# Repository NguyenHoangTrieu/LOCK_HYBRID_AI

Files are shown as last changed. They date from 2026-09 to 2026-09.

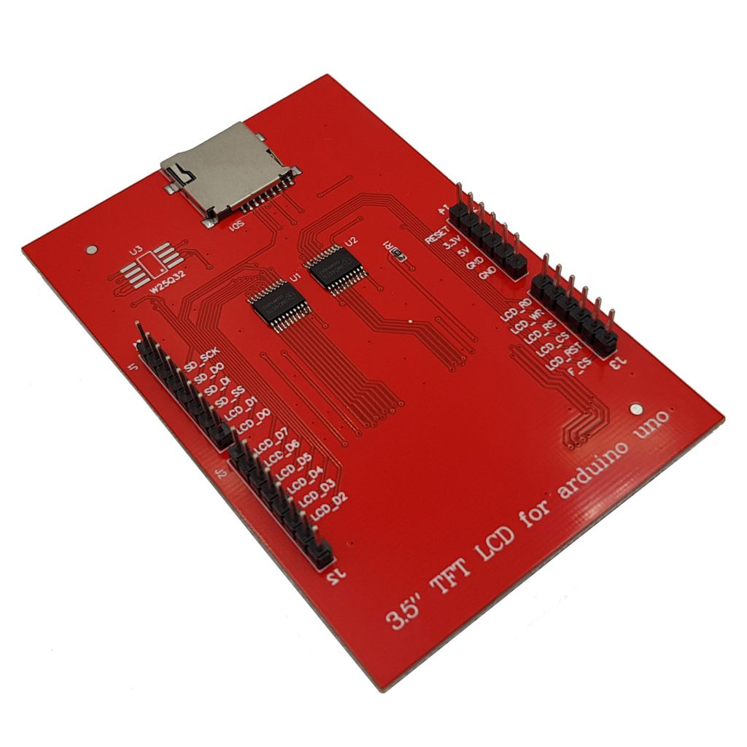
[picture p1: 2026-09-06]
EDGE_NODE/image.png

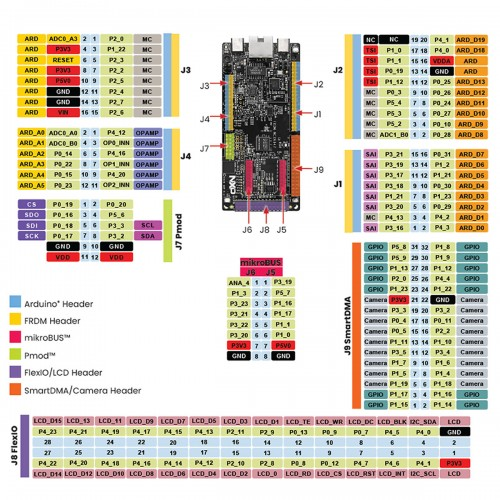
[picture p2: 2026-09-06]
EDGE_NODE/image-1.png

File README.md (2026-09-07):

# LOCK_HYBRID_AI

Face and RFID attendance / access-control system. A door-mounted **Edge AI Node**
detects faces and reads RFID cards; a **Cloud Backend** identifies people, stores
attendance records, and serves an admin web app. Full detail lives in
[ARCHITECTURE.md](ARCHITECTURE.md) (design) and [SYSTEM_REQUIREMENTS.md](SYSTEM_REQUIREMENTS.md)
(requirements, IEEE 830 / ISO-IEC-IEEE 29148 style).

## Why the split

The door device can run a small model that finds faces, but not the much
larger model that identifies them, and it can't hold the user database. So
the device answers *"is someone there?"* and the server answers *"who is
it?"* (CON-7, CON-8 in the SRS).

```mermaid
graph LR
    EDGE["Edge AI Node<br/>detects faces, reads cards, opens the latch"]
    CLOUD["Cloud Backend<br/>identifies people, stores records, serves admin UI"]
    EDGE -->|"face image or card UID"| CLOUD
    CLOUD -->|"decision + unlock command"| EDGE
```

## Repository Layout

```
LOCK_HYBRID_AI/
  ARCHITECTURE.md          <- system design, sequence/state diagrams, build order
  SYSTEM_REQUIREMENTS.md   <- SRS: functional, performance, accuracy, safety requirements
  EDGE_NODE/                <- door-side firmware (FRDM-MCXN947 + camera + RFID + LCD + latch)
    Camera_AI_Test1/          <- camera capture + on-device NPU face-detection bring-up project
  PCB_DES/                  <- hardware / PCB design
    LOCK_EDGE_BASEBOARD/
  CLOUD_SERVER/              <- recognition service, database, admin web app (not yet started)
```

### EDGE_NODE

`EDGE_NODE/Camera_AI_Test1` is the bring-up project for the edge device's
camera + on-NPU face-**detection** pipeline (OV7670 → SmartDMA → Edge
Impulse FOMO model on the Neutron NPU → LCD status / SD snapshot), copied
in from the standalone `Camera_AI_Test1` prototype. It proves out CON-1,
CON-3, and CON-7 from the SRS: an FRDM-MCXN947 board driving an OV7670
camera and running face detection on the integrated NPU without the
general-purpose CPU doing the main computation.

This copy keeps its own `README.md` (build/flash instructions, pinout,
hardware notes) and `ARCHITECTURE.md` (design decisions, NPU integration
details), but drops `KNOWLEDGE.md` (a general concepts primer) and
`WORKLOG.md` (the standalone prototype's dated bring-up log) — those
documented the independent history of the prototype and don't apply once
folded into this repo. The firmware source, board port, and AI model files
are unchanged from the original project.

What still needs to be added on top of this bring-up code to satisfy the
Edge AI Node requirements in the SRS: RFID reader (MFRC522) integration
(HI-2), servo-motor latch control with fail-locked behavior (HI-3, HI-4,
SR-6), the state machine described in ARCHITECTURE.md §2.4, network
communication with the Cloud Backend over the ESP32-C5 DevKit 2.0 (CON-2, CI-1
to CI-5), and offline event buffering (FR-19 to FR-25).

### CLOUD_SERVER

Not yet started. Per ARCHITECTURE.md §3, this will hold the API layer,
recognition service (align → embed → match), attendance service, database,
and the admin web app.

### PCB_DES

Hardware/PCB design files for the edge baseboard (`LOCK_EDGE_BASEBOARD`).

## Build Order

See ARCHITECTURE.md §6 for the full sequencing rationale. In short: bring
up peripherals in isolation, stand up a stub server API, wire the network
path end to end, get card-based attendance fully working with no AI
involved, then bring in the detection model on the device and recognition
on the server.

## Known Limitations (by design, this release)

- **No presentation-attack (spoofing) detection** — a photo of an enrolled
  person may be sufficient to obtain access (SR-7). Sites needing
  protection against this must not rely on face recognition as the sole
  access control.
- Face-based access is not available while offline; only card-based access
  can optionally work offline, using cached authorization data (FR-23,
  FR-24).

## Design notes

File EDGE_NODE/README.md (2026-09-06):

# Camera_AI_Test1

Real-time face-detection camera on **FRDM-MCXN947**. Captures frames from an
OV7670 camera via SmartDMA, runs a single-class ("face") Edge Impulse FOMO
model per frame, and shows the result as a text status line on a TFT panel.
On detection, saves a snapshot (with a box drawn around the face) to the
TFT panel's onboard microSD card, rate-limited to 1 photo/sec.

**Status:** camera + AI + SD snapshot confirmed working on real hardware
(single-core build). The display moved from an 8-bit-parallel shield to a
2.4" SPI TFT module sharing one bus with its microSD slot and XPT2046
touch controller — confirmed working, currently at **7fps** (target
~24fps, next step paused pending further work; see Known Limitations).
Bus-sharing and touch are build-verified only, not yet tested on hardware.
The dual-core RTOS build (see below) is further along — now showing a
live image on real hardware too.

## Overview

Pipeline: `Camera (OV7670/SmartDMA)` → `AI inference (CPU or Neutron NPU)` → `LCD status text`.

Inference runs on either the CPU (CMSIS-NN) or the Neutron NPU (default,
~4ms/inference on real hardware).

- [ARCHITECTURE.md](ARCHITECTURE.md) — design decisions, memory-conflict
  pitfalls, NPU integration details for this specific build.
- [KNOWLEDGE.md](KNOWLEDGE.md) — plain-language explainer of the underlying
  concepts (DVP camera protocol, coprocessors, NPU/quantization, embedded
  RAM/power domains, SWD debug, DCDC voltage conflicts) for anyone new to
  this domain.
- [WORKLOG.md](WORKLOG.md) — full dated bring-up history.
- Original request: [requirement.md](requirement.md).

## Hardware

| Component | Model / Part | Notes |
|---|---|---|
| Board | FRDM-MCXN947 | |
| Camera | OV7670 | → **J9** (SmartDMA/Camera header) |
| Display | 2.4" TFT, 240x320, SPI (ILI9341-family) | → Arduino header (hardware LPSPI1, shared bus) |
| Touch | XPT2046 (on the same TFT module) | → Arduino header, same shared SPI bus; wired up but not read from anywhere in the app - see Known Limitations |
| microSD | TFT panel's onboard slot (SPI mode, FAT-formatted card) | → Arduino D10..D13, same shared SPI bus (hardware LPSPI1) |
| Debug probe | On-board MCU-Link (CMSIS-DAP) | flashing + serial console |

**Board rework required:** change `SJ16`, `SJ26`, `SJ27` from the right side
to the left side before attaching the camera to J9 (per NXP's reference
design).

### Pinout — Camera (OV7670 → J9)

| Camera signal | MCU pin | J9 pin # |
|---|---|---|
| SIOC / SIOD (SCCB) | P3_2 / P3_3 (LP_FLEXCOMM7) | 19 / 20 |
| XCLK | P2_2 (CLKOUT) | 16 |
| PCLK | P0_5 | — |
| HREF | P0_11 | — |
| VSYNC | P0_4 | — |
| D0..D7 | P1_4, P1_5, P1_6, P1_7, P3_4, P3_5, P1_10, P1_11 | 7,8,9,10,11,12,13,14 |
| 3V3 / GND | — | 21 / 22 |

### Pinout — TFT + microSD + touch (Arduino header, ONE shared hardware SPI bus)

2.4" SPI TFT module (ILI9341-family LCD + onboard microSD slot + XPT2046
touch controller). Not a stacking Arduino shield like the previous panel —
wire each pin to the FRDM-MCXN947's Arduino header with jumper wires.

**All three devices share one physical SPI bus** (SCK/MOSI/MISO on Arduino
D13/D11/D12 — the board's only Arduino-header SPI peripheral, hardware
LPSPI1), each with its own chip-select. This is standard wiring for this
class of module (the LCD's SDI/SCK/SDO, the microSD slot's SD_MOSI/SD_SCK/
SD_MISO, and touch's T_DIN/T_CLK/T_DO are 3 silkscreen labels for the same
3 electrical signals) and keeps pin usage low — only 10 Arduino pins used
total, `D0`-`D7` entirely free. See `source/spi1_bus.c` for how the sharing
works (bus init, per-transaction baud-rate reclaiming, chip-select
handling) — **this bus-sharing logic is new and untested on real
hardware**, more so than a single-device SPI driver would be; see Known
Limitations before assuming it's solid.

| Panel pin | Arduino pin | MCU pin | Notes |
|---|---|---|---|
| SCK / SD_SCK / T_CLK | D13 | P0_25 | shared bus, hardware LPSPI1 SCK |
| SDI(MOSI) / SD_MOSI / T_DIN | D11 | P0_24 | shared bus, hardware LPSPI1 SDO (MCU→devices) |
| SDO(MISO) / SD_MISO / T_DO | D12 | P0_26 | shared bus, hardware LPSPI1 SDI (devices→MCU); needs the internal pull-up `pin_mux.c` already enables here |
| LCD CS | A3 | P0_22 | manual GPIO, LCD-only |
| LCD DC | A2 (legacy single-core build) / **D3** (dual-core build) | P0_14 / **P1_23** | manual GPIO, command/data select - moved to GPIO1 for the dual-core build while this pin's real blocker (core1 has no SAU, needs an explicit `PCNS` Non-Secure grant from core0 - see WORKLOG.md's EIGHTH FOLLOW-UP) was still being tracked down; the GPIO1 move itself probably wasn't the fix, granting `PCNS` was, but it's confirmed working as-is so left unchanged |
| LCD RESET | A4 | P0_15 | manual GPIO |
| LCD LED (backlight) | A5 | P0_23 | manual GPIO, driven high in `LCD_Init()` |
| SD_CS | D10 | P0_27 | **real hardware** LPSPI1 PCS0 - SD-only, see below |
| T_CS | D9 | P0_10 | manual GPIO, touch-only |
| T_IRQ | D8 | P0_28 | manual GPIO input (pull-up enabled), active low when touched |
| VCC, GND | board power header | direct | 3.3V or 5V per the panel's regulator — check the specific module |

Only the microSD slot uses the peripheral's real hardware chip-select
(PCS0/D10) — `SDSPI_Init()` needs to flip its active polarity at runtime,
which only works through actual PCS hardware. The LCD and touch each use a
plain GPIO pin for CS instead, toggled manually around every transfer.

**MADCTL (`0x36`) in `lcd_spi_hw.c`'s `LCD_InitPanel()`**: `MV=1`
(rotation) confirmed correct on real hardware. `BGR` was wrong for this
panel (carried over from the old one) — caused a blue/cyan color cast,
fixed by clearing it (`0x28` → `0x20`). If colors or orientation still
look off, adjust `MV`/`MX`/`MY`/`BGR` there.

**Touch (XPT2046) is wired up but unused** — no touch UI in this
pipeline. `touch_xpt2046.c` provides raw, uncalibrated read functions for
a future feature; X/Y channel mapping is a common-convention guess,
unverified on this panel.

## Getting Started

### Prerequisites

- `arm-none-eabi-gcc`, `west` (via the venv at `../../tools/westenv`)
- Local `mcuxsdk` checkout at `../mcuxsdk`
- `pyocd` for flashing over the on-board MCU-Link

### Build / Flash / Run

```bash
./firmware/camera_ai_demo/build.sh          # build, then flash
./firmware/camera_ai_demo/build.sh build    # build only
./firmware/camera_ai_demo/build.sh flash    # flash the last build
./firmware/camera_ai_demo/build.sh monitor  # serial console (115200-8-N-1)
```

`build.sh` runs `west build -b frdmmcxn947 firmware/camera_ai_demo
--toolchain armgcc -Dcore_id=cm33_core0` from the `../mcuxsdk` west
workspace, then flashes the `.elf` via pyOCD, auto-selecting the probe by
its MCU-Link unique ID. See `../../touch_rgb/README.md` for the
probe-permissions/udev-rule note if `pyocd` needs `sudo`.

**If flashing fails with `DebugPortStart`/`ResetCatchClear`/`ResetSystem`
`WAIT ACK`/`FAULT ACK` errors** — a standing probe/pyOCD/CMSIS-Pack quirk on
this board, unrelated to firmware correctness — see
[ARCHITECTURE.md §5](ARCHITECTURE.md#5-debugging--tooling-notes) for the
working recipe (`nxpdebugmbox` + specific pyOCD flags).

### Dual-core RTOS build (see WORKLOG.md)

A separate, opt-in build (`-DDUALCORE_RTOS=ON`, default `OFF`) boots core1
and splits the app across both cores: core1 runs camera capture + LCD push
+ SD snapshot (`source/main_core1.c`), core0 runs AI inference only
(`source/main_core0.c`), both under FreeRTOS, talking over MCMGR
mailbox-event doorbells (`source/shared/ipc_events.*`) and a shared frame
buffer (`source/shared/ipc_layout.h`) — no RPMsg-Lite. Full migration
history/stage-by-stage bring-up: [ARCHITECTURE.md](ARCHITECTURE.md),
[WORKLOG.md](WORKLOG.md).

This is a **completely separate build directory and command set** from the
single-core build above — the two never share build artifacts and flashing
one never disturbs the other:

```bash
./firmware/camera_ai_demo/build.sh dualcore-build   # build core1, then core0 (core0 embeds core1's image)
./firmware/camera_ai_demo/build.sh dualcore-flash   # flash core0's combined .elf - one flash op, core1 rides along
./firmware/camera_ai_demo/build.sh dualcore-all     # both of the above
./firmware/camera_ai_demo/build.sh monitor          # same serial console works for either build
```

Notes specific to this build:

- **core1 must always build before core0** — core0's link step `.incbin`s
  core1's raw `.bin` (see `board_port/cm33_core0/app.h`), which needs
  core1's build directory to already exist. `dualcore-build` always does
  both in the right order and also force-deletes core0's cached
  `fsl_incbin.S` object file first, since Ninja has no way to know that
  `.incbin` depends on core1's binary — without that, core0 can silently
  re-link a **stale** embedded core1 image after only core1's source
  changed. Always use `dualcore-build` (not a manual `west build` for a
  single core) when iterating, especially on core1 code.
- No `rebuild`/`clean` equivalent for `build_dualcore/` yet — remove it by
  hand (`rm -rf firmware/camera_ai_demo/build_dualcore`) for a truly clean
  dual-core rebuild.
- **The `LCD_CAMERA_PREVIEW`, `AI_MODEL_USE_NPU`, `LCD_ARDUINO_HEADER_BITBANG`,
  and `USB_STREAM_DIAGNOSTIC_DISABLE` flags documented above do NOT apply
  to this build** — `CMakeLists.txt`'s `DUALCORE_RTOS` branch `return()`s
  before any of those `option()`s are even declared. Core1's
  `CameraLcdTask` always runs one fixed loop (camera preview + AI overlay
  + rate-limited snapshot together); there is currently no dual-core
  equivalent of the AI-off, preview-only diagnostic build.
- **Status: Stage 5, CONFIRMED SHOWING A LIVE IMAGE on real hardware
  (2026-09-06)** — camera, LCD push, the core0 AI round-trip, SD
  snapshot, and the on-screen image are all confirmed working. Still
  open: LCD tearing under the cross-core IPC interrupt hasn't been
  re-checked now that the image is visible, and SD write reliability
  degrades after the first few snapshots in a session. See WORKLOG.md's
  latest entries before assuming full stability.
- **Adding a new GPIO pin for core1 to drive? Read this first.** core1
  has no SAU, so it's permanently Non-Secure — GPIO blocks Non-Secure pin
  access per-pin by default (`PCNS` register). An ungranted pin doesn't
  error, it just silently does nothing. Grant it from **core0** before
  `MCMGR_StartCore()` — see `main_core0.c`'s `GPIO0->PCNS`/`GPIO1->PCNS`
  lines, WORKLOG.md's EIGHTH FOLLOW-UP entry, and KNOWLEDGE.md §9.

### Expected output on success

```
Camera_AI_Test1 - FRDM-MCXN947
Camera: OV7670 on J9 SmartDMA/Camera header
Display: Arduino-header LCD status text (camera + AI hook)

Camera: OV7670 detected on J9 (PID=0x76 VER=0x73 confirmed), 320x240 @ 30 fps.
AI_MODEL_Init: Neutron NPU face detector ready (72x72 input, 1 class(es), arena used 94388/122880 bytes)
LCD: hardware SPI (LPSPI1, shared bus) on the Arduino header
AI_MODEL_RunInference: total classifier time = 3957us (3ms)
AI result: box[0] label=face x=<N> y=<N> w=<N> h=<N> score=<N>%
```

LCD shows two text lines — `FACE: 1`/`FACE: 0`, and `CAPTURE: 1`/`CAPTURE: 0`
(lit for 4s right after a snapshot is saved, see "Snapshot on Face
Detection" below) — not a live image.

## Configuration

Pass any of these to `build`/`rebuild`/`all` as `-D<FLAG>=ON|OFF`.

| Flag | Default | Effect |
|---|---|---|
| `AI_MODEL_USE_NPU` | `ON` | Inference backend: Neutron NPU (`ON`, ~4ms/inference) vs. CPU + CMSIS-NN via Edge Impulse SDK (`OFF`). Same detection logic either way. |
| `LCD_CAMERA_PREVIEW` | `OFF` | Skip AI, stream raw camera feed to the LCD as fast as frames arrive — for focusing the lens by eye. Prints `LCD preview: N fps` once/sec over UART — see Known Limitations for the fps math/target. |
| `LCD_ARDUINO_HEADER_BITBANG` | `ON` | `ON`: drive TFT via hardware SPI on the Arduino header, shared with the microSD/touch bus (default). `OFF`: J8 header (FlexIO/bit-bang) — abandoned, no touch/SD sharing there, see [ARCHITECTURE.md §4](ARCHITECTURE.md#4-known-constraints--trade-offs). |
| `USB_STREAM_DIAGNOSTIC_DISABLE` | `ON` | `OFF` opts into the abandoned UVC webcam streaming path (doesn't drive the LCD) — see [ARCHITECTURE.md §4](ARCHITECTURE.md#4-known-constraints--trade-offs). |

`AI_MODEL_USE_NPU` and `LCD_CAMERA_PREVIEW` are independent of the LCD/USB
flags; combining `LCD_CAMERA_PREVIEW=ON` with
`USB_STREAM_DIAGNOSTIC_DISABLE=OFF` builds but isn't a meaningful
combination.

### Example commands

```bash
# Default build (Neutron NPU, camera+AI+LCD status text, no USB)
./firmware/camera_ai_demo/build.sh build

# Lens-focus diagnostic: raw camera feed straight to the LCD, no AI
./firmware/camera_ai_demo/build.sh build -DLCD_CAMERA_PREVIEW=ON

# CPU + CMSIS-NN inference instead of the Neutron NPU
./firmware/camera_ai_demo/build.sh build -DAI_MODEL_USE_NPU=OFF

# J8 header (FlexIO) instead of the Arduino header's SPI panel - abandoned, see ARCHITECTURE.md §4
./firmware/camera_ai_demo/build.sh build -DLCD_ARDUINO_HEADER_BITBANG=OFF

# Flags combine freely - build only (no flash), CPU backend + lens-focus preview
./firmware/camera_ai_demo/build.sh build -DAI_MODEL_USE_NPU=OFF -DLCD_CAMERA_PREVIEW=ON
```

`build` builds without flashing; `all` (or bare `./build.sh`) builds then
flashes; `rebuild` cleans `build/` first - needed when switching flags
that change which files compile, since flags otherwise stick in the CMake
cache.

## AI Model

Edge Impulse project **"Face_Detection_NXP"** (ID `1095726`, deploy v2),
FOMO detector, 72x72 int8 input, single class `face`, trained on
WIDER FACE + DarkFace (**both CC-BY-NC-ND/research-only — not cleared for
commercial use as-is**).

| | Neutron NPU (default) | CPU + CMSIS-NN |
|---|---|---|
| Build flag | (default) | `-DAI_MODEL_USE_NPU=OFF` |
| Source | `source/ai/model_runner_npu.cpp` | `source/ai/model_runner.cpp` |
| Tensor arena | 120KB static (`m_data`), 94,388 bytes used | 112,460 bytes (`m_sramx` primary + `m_data` overflow) |
| Measured on hardware | ~3.96ms/inference | not yet separately measured for this model |

To swap in a different/retrained model: re-export from Edge Impulse Studio
(new C++ library for the CPU path; new `.tflite` run through
`neutron_converter` for the NPU path) and update
`model_runner.cpp`/`model_runner_npu.cpp` if tensor shapes or class labels
changed. See [ARCHITECTURE.md §2](ARCHITECTURE.md#2-components) for how
the NPU conversion and integration actually work.

## Snapshot on Face Detection

On face detection, `snapshot.c` draws a green box (via `bbox_overlay.c`)
into the frame buffer and saves it as an uncompressed 16-bit BMP
(`FACE0001.BMP`, ...) to the SD card, rate-limited to 1 capture/sec.
Filenames never overwrite a previous session's snapshots.

The box is the model's raw grid-cell box (small relative to a real face,
since FOMO doesn't regress an actual box size) - a cosmetic expansion was
tried and reverted on purpose. See
[ARCHITECTURE.md §2](ARCHITECTURE.md#2-components).

The LCD shows a `CAPTURE: 1` status line for 4s after each save (the box
itself is only in the saved file, never drawn on the LCD). No SD card →
logged once at boot, then snapshot capture silently no-ops every frame
after.

Every save logs how long the actual SD card write took (DWT cycle
counter, same technique `AI_MODEL_RunInference` uses):
```
Snapshot: saved FACE0030.BMP (write took 187342us, 187ms)
```
Originally ~3.3s/save - the SD bus was stuck at the 400kHz identification
speed instead of switching up. Fixed (`SD_SPI_OPERATING_BAUDRATE`, now
8MHz); see [WORKLOG.md](WORKLOG.md).

Writes the frame buffer directly to the file with one `f_write()` call -
no second full-frame buffer needed, which matters since `m_data` is
already >90% used. See [ARCHITECTURE.md §2](ARCHITECTURE.md#2-components).

## Project Structure

```
Camera_AI_Test1/
  README.md, ARCHITECTURE.md, WORKLOG.md, requirement.md
  firmware/camera_ai_demo/
    CMakeLists.txt, prj.conf, build.sh
    board_port/            <- pin muxing, hardware_init.c, ei_sramx.ld (board.c/clock_config.c come from the SDK)
    source/
      main.c                <- capture -> AI inference -> LCD status-text loop
      fault_handler.c        <- HardFault register-decode dump handler
      spi1_bus.c/h            <- shared hardware LPSPI1 bus (LCD + microSD + touch), see file header comment
      camera/                <- OV7670 + SmartDMA driver (from NXP reference)
      display/                <- lcd_spi_hw.c (default, Arduino header, hardware SPI), touch_xpt2046.c (Arduino header only), lcd_bitbang.c/lcd_flexio_mculcd.c (abandoned J8 path), text_overlay.c
      ai/
        model_runner.h        <- shared inference API, both backends implement
        model_runner.cpp      <- CPU + CMSIS-NN backend
        model_runner_npu.cpp  <- Neutron NPU backend (default)
        ei_sramx_alloc.c/h    <- custom allocator for the CPU path's tensor arena in m_sramx
        edge_impulse/          <- Edge Impulse C++ library export
        neutron/                <- NPU-converted model (tflite_learn_..._npu.tflite/.h)
      usb/                    <- abandoned UVC streaming path
      storage/
        snapshot.c/h           <- rate-limited box-draw + BMP save on face detection
        sd_spi_disk.c/h         <- shared-bus SD-over-SPI + FatFs diskio glue (see ARCHITECTURE.md §2)
        ffconf.h                 <- hand-written FatFs config (RAM-minimal: FF_FS_TINY=1, no LFN)
```

## Known Limitations

- LCD shows text status lines only, not a live image or bounding boxes
  (by design, to save RAM — see "Abandoned Features" below); the box drawn
  on face detection only ever exists in the saved BMP file.
- CPU-path inference timing for the current model hasn't been separately
  measured on hardware yet (NPU path is measured: ~4ms/inference).
- Not yet validated against a real face specifically — pipeline (capture →
  resize → inference → decode) confirmed working end-to-end with real
  non-flat camera data, but detection accuracy is only backed by Edge
  Impulse Studio's validation/test-set metrics so far (see WORKLOG.md).
- The Arduino-header panel is a 2.4" SPI TFT module sharing one bus with
  its onboard microSD slot and XPT2046 touch controller. **LCD path
  confirmed on real hardware** (correct orientation, no corruption; one
  bug found and fixed - `BGR` was wrong, causing a blue/cyan cast).
  Bus-sharing baud-reclaim logic and touch are still build-verified only,
  not tested on hardware - suspect them first if SD snapshots ever come
  back corrupted (`sd_spi_disk.c`, `lcd_spi_hw.c`).
- **fps target (~24fps) not reached - confirmed at 7fps**, up from 2fps
  via two real-hardware bug fixes (missing `kLPSPI_MasterPcsContinuous`
  flag; `SPI1_BUS_SetBaudRate()` not recomputing per-transfer delay
  registers) - see WORKLOG.md for the full trail. **eDMA was attempted
  and abandoned** - hung on real hardware (RX eDMA channel never signals
  done), root cause not found; reverted to the working CPU-polled path.
  If the image looks glitchy/torn at 24MHz, lower `LCD_SPI_BAUDRATE_HZ`
  toward 2-6MHz first.
- SD card mount/init **confirmed working on real hardware**, after fixing
  5 separate bugs (boot hang, a floating MISO line needing an internal
  pull-up, a false timeout on every write, missing font glyphs) - see
  [WORKLOG.md](WORKLOG.md) /
  [ARCHITECTURE.md §5](ARCHITECTURE.md#5-debugging--tooling-notes). Not
  yet separately confirmed: an actual face-triggered capture succeeding
  end-to-end.

## Abandoned Features

Not part of the current default build; kept in the tree (still compile in
most cases) for reference. Full trail in [WORKLOG.md](WORKLOG.md).

| Feature | Why abandoned | Still buildable via |
|---|---|---|
| Live camera image + bounding-box overlay on LCD | Too much data over the bit-bang bus per frame; reverted to 1-line text status | `source/display/bbox_overlay.c/h` (no longer unused — reused by the SD snapshot feature above, just not drawn to the LCD) |
| J8 FlexIO LCD header (hardware-accelerated bus) | Wiring/init confirmed good, but pixel data came out as noise — unresolved bus-speed/signal-integrity issue | `-DLCD_ARDUINO_HEADER_BITBANG=OFF` |
| USB Video Class (UVC) webcam streaming | Genuine hardware conflict, not fixable in software — see [ARCHITECTURE.md §4](ARCHITECTURE.md#4-known-constraints--trade-offs) | `-DUSB_STREAM_DIAGNOSTIC_DISABLE=OFF` (won't drive the LCD) |

## History

Started on the Arduino-header TFT design, briefly tried J8 FlexIO and USB
Video Class as alternatives (both abandoned - see table above), then
camera+LCD bring-up, AI integration (see
[ARCHITECTURE.md §3](ARCHITECTURE.md#3-key-design-decisions)), and the
Neutron NPU backend as a speed upgrade. The model itself started as a
3-class drowsy-eye detector, later swapped for the current single-class
`face` detector. Full dated trail: [WORKLOG.md](WORKLOG.md).
</content>

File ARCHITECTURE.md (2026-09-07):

# System Architecture and Design
## Face and RFID Attendance System

**Version:** 2.0
**Companion document:** `SYSTEM_REQUIREMENTS.md`

This document describes how the system is built. Every design decision here exists to satisfy a requirement in the SRS; where the connection is not obvious, the relevant requirement is cited.

Diagrams are kept deliberately small. Each one answers a single question. A diagram that tries to show everything at once shows nothing clearly.

---

## 1. Context: The Two Halves

At the highest level there are only two things and one link between them.

```mermaid
graph LR
    EDGE["<b>Edge AI Node</b><br/>at the door<br/><br/>Detects faces<br/>Reads cards<br/>Opens the latch"]
    CLOUD["<b>Cloud Backend</b><br/>on a server<br/><br/>Identifies people<br/>Stores records<br/>Serves admin UI"]

    EDGE -->|"face image or card UID"| CLOUD
    CLOUD -->|"decision + unlock command"| EDGE
```

**Why the split falls here.** The processor at the door can run a small model that finds faces. It cannot run the much larger model that identifies them, and it cannot hold the user database. So the device answers *"is someone there?"* and the server answers *"who is it?"* (CON-7, CON-8).

Everything else in this document is an expansion of one of these two boxes, or of the link between them.

---

## 2. The Edge AI Node

### 2.1 Physical Connections

The controller sits in the middle. Everything else connects to it. Nothing connects to anything else.

```mermaid
graph TD
    CAM["Camera<br/>OV7670"]
    RFID["Card Reader<br/>MFRC522"]
    MCU["<b>FRDM-MCXN947</b><br/>controller + NPU"]
    LCD["Display<br/>2.4in TFT"]
    MOTOR["Servo Motor<br/>door latch"]
    ESP["Wi-Fi Module<br/>ESP32-C5 DevKit 2.0"]

    CAM -->|"DVP + SmartDMA"| MCU
    RFID -->|"SPI"| MCU
    MCU -->|"SPI"| LCD
    MCU -->|"GPIO PWM"| MOTOR
    MCU <-->|"SPI"| ESP
```

### 2.2 What Each Part Does

| Part | Role | Notes for implementation |
|---|---|---|
| **MCXN947** | Owns the state machine, runs the detection model on the NPU, drives every peripheral | The only component that makes decisions |
| **OV7670** | Streams raw frames | No onboard JPEG. Configure over SCCB at boot, then pull frames with SmartDMA — this is the peripheral NXP provides for DVP capture on MCX N |
| **MFRC522** | Reports a card UID when one is present | Makes no access decision (FR-10) |
| **TFT display** | Output only | Must never block other work — a long display write during a card tap loses the tap |
| **Servo motor** | Output only | Needs its own power rail. Defaults to locked (SR-6) |
| **ESP32-C5 DevKit 2.0** | Network transport only | Deliberately contains no business logic, so all security-relevant code stays in one place |

### 2.3 Firmware Structure

The firmware is organized as concurrent tasks around a single state machine. Events flow inward; commands flow outward.

```mermaid
graph LR
    subgraph IN["Input tasks"]
        A["Camera<br/>capture"]
        B["Inference<br/>face detect"]
        C["RFID<br/>poll"]
    end

    SM["<b>State<br/>Machine</b>"]

    subgraph OUT["Output tasks"]
        D["Display"]
        E["Actuator"]
    end

    NET["Network<br/>task"]

    A --> B
    B --> SM
    C --> SM
    SM --> D
    SM --> E
    SM <--> NET
```

**Three rules that prevent the usual embedded bugs:**

1. **Only the state machine changes state.** Other tasks send it events. They never mutate state themselves. Without this rule, two subsystems eventually disagree about what the device is doing.
2. **Output tasks never block.** The display and actuator run independently so a slow render cannot cause a missed card tap.
3. **The actuator defaults to locked.** If anything anywhere fails, the door stays shut (SR-6).

The camera task uses a double buffer, so inference runs on one frame while the next is being captured. This is what makes the 5 fps target (PR-3) achievable.

### 2.4 Device States

```mermaid
stateDiagram-v2
    [*] --> Boot
    Boot --> Idle: ready
    Boot --> Fault: init failed

    Idle --> Waiting: face stable
    Idle --> Waiting: card tapped
    Idle --> Offline: link lost

    Waiting --> Granted: approved
    Waiting --> Denied: rejected
    Waiting --> Offline: timeout

    Granted --> Idle: latch relocked
    Denied --> Idle: message shown
    Offline --> Idle: link restored

    Fault --> Boot: watchdog reset
```

| State | Display shows | Latch |
|---|---|---|
| `Boot` | Starting up | Locked |
| `Idle` | Ready | Locked |
| `Waiting` | Processing | Locked |
| `Granted` | Welcome, {name} | **Unlocked** |
| `Denied` | Not recognized | Locked |
| `Offline` | Offline mode | Locked |
| `Fault` | Service unavailable | Locked |

Note that the latch is unlocked in exactly one state. That is the whole of the access control logic on the device.

---

## 3. The Cloud Backend

### 3.1 Internal Structure

```mermaid
graph TD
    API["<b>API Layer</b><br/>authenticates devices<br/>routes requests"]
    REC["<b>Recognition Service</b><br/>align → embed → match"]
    ATT["<b>Attendance Service</b><br/>cooldown rules<br/>writes records"]
    DB[("<b>Database</b>")]
    WEB["<b>Admin Web App</b><br/>enrollment, reports"]

    API --> REC
    API --> ATT
    REC --> DB
    ATT --> DB
    WEB --> DB
```

### 3.2 The Recognition Pipeline

This is the sequence inside the Recognition Service. It runs left to right with no branching until the final comparison.

```mermaid
graph LR
    A["Face image<br/>received"] --> B["Find<br/>landmarks"]
    B --> C["Align to<br/>standard pose"]
    C --> D["Generate<br/>embedding"]
    D --> E["Compare against<br/>enrolled set"]
    E --> F["Score"]
```

| Stage | What it does | How |
|---|---|---|
| **Find landmarks** | Locates eyes, nose, mouth corners | Detection model with landmark output |
| **Align** | Rotates and scales so the face sits in a standard position | Similarity transform — pure geometry, not a neural network |
| **Embed** | Turns the aligned face into a fixed-length vector | ArcFace (recommended) or FaceNet |
| **Compare** | Measures similarity against every enrolled embedding | Cosine similarity; brute force is fast enough below a few thousand users (ASM-3) |
| **Score** | Best match, compared against the configured threshold | Threshold is configurable (AR-3) |

### 3.3 Model Choices

**On the device — detection only.** The model must be INT8 quantized and compiled for the Neutron NPU, with a small input size such as 128×128. Candidates: Ultra-Light-Fast-Generic-Face-Detector, BlazeFace, or a face detector from the NXP eIQ Model Zoo. The Model Zoo option has the practical advantage of already being validated on this silicon.

**On the server — recognition.** ArcFace with a ResNet backbone is the recommended choice, producing 512-dimensional embeddings. FaceNet is a lighter alternative producing 128-dimensional embeddings.

Do not select a model on published benchmarks alone. Requirement AR-4 says accuracy is measured on this hardware at the installation site, and the gap between benchmark and reality is usually large.

---

## 4. Main Flows

Each flow is shown twice: once as an exchange between systems, and once as the detail inside whichever system does the interesting work. This keeps each diagram narrow enough to read.

### 4.1 Face Attendance — Between Systems

```mermaid
sequenceDiagram
    actor U as Person
    participant E as Edge Node
    participant S as Server
    participant D as Database

    U->>E: Stands in front of camera
    Note over E: Confirms face is stable
    E->>E: Crop and compress
    E->>S: Face image + timestamp
    Note over E: Display: "Processing"

    S->>S: Align, embed
    S->>D: Fetch enrolled embeddings
    D-->>S: Embeddings
    S->>S: Compare, apply threshold

    alt Match found
        S->>D: Write attendance record
        S-->>E: Granted + name + unlock
        Note over E: Display: "Welcome"
        E->>E: Unlock, hold, relock
    else No match
        S->>D: Write denied record
        S-->>E: Denied
        Note over E: Display: "Not recognized"
    end
```

### 4.2 Face Attendance — Inside the Edge Node

```mermaid
graph TD
    A["Capture frame"] --> B["Run detection<br/>on NPU"]
    B --> C{"Face<br/>present?"}
    C -->|No| A
    C -->|Yes| D["Increment<br/>stability counter"]
    D --> E{"Stable for<br/>3 frames?"}
    E -->|No| A
    E -->|Yes| F["Crop with margin,<br/>resize, compress"]
    F --> G["Send to server"]
    G --> H{"Response<br/>within 5s?"}
    H -->|No| I["Treat as denied"]
    H -->|Yes| J{"Granted?"}
    J -->|Yes| K["Unlock, hold,<br/>relock"]
    J -->|No| I
    K --> A
    I --> A
```

The stability counter implements FR-2. Without it, the system fires at everyone who walks past the door.

### 4.3 Face Attendance — Inside the Server

```mermaid
graph TD
    A["Request received"] --> B{"Device<br/>authenticated?"}
    B -->|No| R1["Reject"]
    B -->|Yes| C["Align and embed"]
    C --> D{"Face found<br/>in image?"}
    D -->|No| R2["Return: no face"]
    D -->|Yes| E["Compare against<br/>enrolled embeddings"]
    E --> F{"Best score above<br/>threshold?"}
    F -->|No| R3["Log denied<br/>Return: no match"]
    F -->|Yes| G{"Within cooldown<br/>window?"}
    G -->|Yes| R4["Skip record<br/>Return: granted"]
    G -->|No| H["Write record"]
    H --> R5["Return: granted"]
```

**The cooldown branch is worth pausing on.** If someone was recorded five minutes ago and comes back, we still open the door — we simply do not write a second attendance record. Refusing entry because attendance was already taken would be a poor experience, and requirement FR-14 forbids it.

### 4.4 Card Attendance

Simpler, because no AI is involved on either side. The device is purely a relay.

```mermaid
sequenceDiagram
    actor U as Person
    participant E as Edge Node
    participant S as Server
    participant D as Database

    U->>E: Taps card
    E->>S: Card UID + timestamp
    Note over E: Display: "Processing"
    S->>D: Look up UID
    D-->>S: User record or none

    alt Found and active
        S->>D: Write attendance record
        S-->>E: Granted + name + unlock
        E->>E: Unlock, hold, relock
    else Unknown or deactivated
        S->>D: Write denied record
        S-->>E: Denied
    end
```

**Why the UID is never checked on the device (FR-10).** If it were, revoking a lost card would mean reprogramming every door in the building. Keeping the decision on the server makes revocation instant and central.

### 4.5 Offline Operation

```mermaid
sequenceDiagram
    participant E as Edge Node
    participant F as Local Flash
    participant S as Server

    Note over E: Send fails — no link
    E->>F: Buffer event with timestamp
    Note over E: Display: "Offline mode"

    loop Every 30 seconds
        E->>S: Connectivity check
        S--xE: No response
    end

    S-->>E: Link restored
    E->>F: Read buffered events
    E->>S: Upload batch
    S-->>E: Per-event confirmations
    E->>F: Delete confirmed events
    Note over E: Display: "Ready"
```

**Two details that are easy to get wrong:**

Events carry the time they *happened*, not the time they were uploaded (FR-21). An event buffered at 08:00 and uploaded at 11:00 must appear in the record as 08:00.

Events are deleted from flash only after the server confirms each one (FR-22). Deleting on upload rather than on confirmation loses records whenever a connection drops mid-transfer.

### 4.6 Enrollment

Happens entirely through the web application. No device involvement.

```mermaid
sequenceDiagram
    actor A as Administrator
    participant W as Web App
    participant S as Server
    participant D as Database

    A->>W: Create user, upload 3-5 photos
    W->>S: Submit

    loop Each photo
        S->>S: Detect, align, embed
    end

    S->>S: Average into one embedding
    S->>D: Store user + embedding
    S->>S: Discard original photos
    S-->>W: Enrolled

    opt Assign card
        A->>W: Enter card UID
        W->>S: Update user
        S->>D: Store UID
    end
```

**Why several photos.** One photo captures one lighting condition and one angle. Averaging across several gives a more robust representation and measurably reduces false rejections (AR-2).

**Why the originals are discarded (DR-2).** An embedding cannot be reversed back into a usable photograph. Keeping only embeddings means a database breach leaks far less than a breach of a photo archive would.

---

## 5. Interface Design

### 5.1 Device to Server

Communication is request-response over HTTPS. The device is always the initiator; the server never pushes.

| Purpose | Direction | Carries |
|---|---|---|
| Face attendance | Device → Server | Cropped face image, device ID, timestamp |
| Card attendance | Device → Server | Card UID, device ID, timestamp |
| Batch upload | Device → Server | Array of buffered events |
| Configuration fetch | Device → Server | Device ID; returns thresholds and durations |
| Heartbeat | Device → Server | Device ID; server updates last-seen |
| Decision | Server → Device | Outcome, name if identified, unlock command and duration, message to display |

Each device authenticates with a unique credential (CI-2). The decision response includes the display message rather than the device composing it, so wording can be changed centrally.

### 5.2 Data Volumes

| Link | Payload | Approximate size |
|---|---|---|
| Face event | Cropped JPEG | 10–30 KB |
| Card event | UID + metadata | under 100 bytes |
| Decision | JSON response | under 500 bytes |

The face event is the only payload large enough to threaten the 2-second target (PR-1). This is the measurement called for by open issue OI-2.

---

## 6. Build Order

Sequenced so that each phase produces something testable, and so the riskiest unknowns surface early.

| Phase | Work | Proves |
|---|---|---|
| **1** | Bring up each peripheral in isolation — camera dumping a frame, display showing a test pattern, reader returning a UID, motor turning | The hardware works |
| **2** | Server API with a stub recognizer that always grants, plus the database schema | The device team has something real to develop against |
| **3** | End-to-end network path with dummy data | The integration pain is found early, not late |
| **4** | Full card attendance flow | The whole architecture works, with no AI involved |
| **5** | Detection model on the NPU; benchmark frame rate; tune the stability filter | PR-3 is achievable |
| **6** | Real recognition on the server; tune the threshold against enrolled users | AR-1 and AR-2 are achievable |
| **7** | Offline buffering, admin web app, hardening | The remaining requirements |

Phase 4 before Phase 5 is deliberate. Card attendance exercises every part of the architecture except the models. If something structural is wrong, it is far cheaper to find out before the AI work starts.

---

## 7. Design Risks

| Risk | Consequence | What to do |
|---|---|---|
| Camera performs poorly in low light (OI-1) | AR-1 and AR-2 missed at an entrance in the evening | Test under real lighting in Phase 1. Be prepared to add illumination or change the camera |
| Device-to-network bandwidth insufficient (OI-2) | PR-1 missed on face attendance | Measure in Phase 3. Reduce image size or compression quality if needed |
| Detection model too slow on the NPU | PR-3 missed; sluggish response | Benchmark several candidates in Phase 5. Reduce input resolution if needed |
| Flash too small for offline face buffering (OI-3) | RR-5 partly unmet | Fall back to buffering card events only, and refuse face attendance while offline |
| No software JPEG encoder on the device | CPU cost eats into PR-1 | Measure whether sending a raw downscaled image is cheaper end to end than compressing first |
| **Photograph spoofing (SR-7)** | Unauthorized access using a printed or on-screen photo | Documented as a known limitation of this release. Sites needing protection must not use face recognition as sole access control |

The last row is not a risk to be managed away by careful engineering. It is a property of the system as scoped. It must be stated to whoever deploys it.

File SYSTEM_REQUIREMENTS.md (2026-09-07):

# Software Requirements Specification
## Face and RFID Attendance System

**Version:** 2.0
**Status:** Draft for review
**Structure:** Based on IEEE 830 / ISO-IEC-IEEE 29148, adapted for an embedded system

---

## 1. Introduction

### 1.1 Purpose

This document states what the Face and RFID Attendance System must do and how well it must do it. It is written for the engineers who will design and build the system, and for the stakeholders who need to confirm that the right product is being built.

This document describes **requirements only**. It does not describe how those requirements will be met. Design decisions — module structure, interfaces, algorithms, data formats — belong in the architecture and design documents.

### 1.2 Scope

The system records the attendance of people entering a controlled space, and controls a door latch based on whether the person is authorized.

A person identifies themselves in one of two ways: by standing in front of a camera, or by tapping an RFID card. The system determines who they are, records the event, and unlocks the door if they are authorized.

The system consists of a device installed at the door and a server that performs recognition and stores records. Administrators manage users and view reports through a web interface.

**In scope:** attendance recording, door access control, user enrollment, card management, attendance reporting, offline resilience.

**Not in scope for this release:** liveness or anti-spoofing detection, recognition of multiple people simultaneously, multi-site device management, an end-user mobile application, integration with external payroll or HR systems.

### 1.3 Definitions and Abbreviations

| Term | Meaning |
|---|---|
| **Edge AI Node** | The physical unit installed at the door. Contains the camera, card reader, display, latch actuator, and processing hardware. |
| **Cloud Backend** | The server that performs face recognition, stores records, and hosts the administration interface. |
| **Face detection** | Determining whether a face is present in an image and where it is. Does not identify the person. |
| **Face recognition** | Determining the identity of a person from an image of their face. |
| **Face embedding** | A fixed-length numeric vector that represents a face. Two embeddings of the same person are numerically close; two embeddings of different people are far apart. |
| **Enrollment** | The process of registering a new person so the system can subsequently recognize them. |
| **UID** | The unique identifier stored on an RFID card. |
| **False acceptance** | The system grants access to a person who is not authorized. |
| **False rejection** | The system denies access to a person who is authorized. |
| **Cooldown** | A period after a recorded attendance event during which the same person's repeat presentations are not recorded again. |
| **NPU** | Neural Processing Unit — hardware that accelerates AI model execution. |

### 1.4 References

- IEEE 830-1998, Recommended Practice for Software Requirements Specifications
- ISO/IEC/IEEE 29148:2018, Requirements engineering
- `ARCHITECTURE.md` — the companion design document for this system

### 1.5 How to Read This Document

Section 2 gives the general picture: what the product is, who uses it, and what limits it operates under. Section 3 states the requirements in detail. Each requirement has an identifier so it can be referenced in design documents, test plans, and change requests.

Requirements use the word **shall** for mandatory behavior and **should** for recommended behavior.

---

## 2. Overall Description

### 2.1 Product Perspective

This is a new, self-contained system. It does not replace an existing system and does not depend on any external service beyond standard network infrastructure.

The system spans two physical locations. A device at the door handles interaction with the person. A server handles identification and record keeping. The two communicate over a network connection.

The division of work between them is driven by a hardware constraint: the processor in the door device can run a small model that finds faces in an image, but it cannot run the much larger model required to identify a person, nor can it hold the database of enrolled users. Identification therefore happens on the server.

### 2.2 Product Functions

At a high level the system provides:

**Attendance by face.** A person stands in front of the device. The system determines their identity from their face, records the attendance event, and unlocks the door if authorized.

**Attendance by card.** A person taps an RFID card. The system determines their identity from the card, records the event, and unlocks the door if authorized.

**Visual feedback.** The device tells the person what is happening at every moment: ready, working, granted, denied, or unavailable.

**Door control.** The device physically unlocks and relocks the door latch.

**Offline operation.** When the network is unavailable, the device continues to accept card presentations, stores the events locally, and uploads them when the connection returns.

**User management.** Administrators register new people, capture their faces, assign and revoke cards, and deactivate people who leave.

**Reporting.** Administrators view and export attendance records.

**Device monitoring.** Administrators can see whether each door device is online.

### 2.3 User Classes

| User class | Description | Technical skill | Frequency of use |
|---|---|---|---|
| **Attendee** | An employee or student who uses the system to record attendance and enter the space. Interacts only with the door device. | None assumed. The interaction must be obvious without instruction. | Several times a day |
| **Administrator** | Registers users, manages cards, runs reports. Uses the web interface. | Comfortable with ordinary web applications. Not a technical specialist. | Daily to weekly |
| **System maintainer** | Installs devices, configures thresholds, diagnoses faults. | Technical. | Rarely, after installation |

### 2.4 Operating Environment

The door device operates indoors, at an entrance. Lighting conditions vary through the day and are not controlled. Ambient temperature is normal indoor range. The device is mains powered and connected to the site's wireless network.

The server operates in a normal server environment, either cloud-hosted or on-premise. The administration interface is accessed through a standard web browser on a desktop computer.

### 2.5 Design and Implementation Constraints

These are fixed inputs to the project, not choices open to the design team.

| ID | Constraint |
|---|---|
| CON-1 | The door device shall be built on the NXP FRDM-MCXN947 development board. |
| CON-2 | Network connectivity shall be provided by an ESP32-C5 DevKit 2.0 module. |
| CON-3 | Image capture shall use an OV7670 camera module. |
| CON-4 | Card reading shall use an MFRC522 RFID reader operating at 13.56 MHz. |
| CON-5 | User feedback shall be presented on a 2.4 inch SPI TFT display. |
| CON-6 | The door latch shall be driven by a servo motor. |
| CON-7 | Face detection shall execute on the integrated NPU of the MCXN947. Detection shall not depend on the general-purpose CPU for its main computation. |
| CON-8 | Face recognition shall execute on the server. It shall not execute on the door device. |
| CON-9 | Available flash memory on the device limits how much data can be buffered offline. The offline buffering requirements shall be met within this limit. |

### 2.6 Assumptions and Dependencies

| ID | Assumption |
|---|---|
| ASM-1 | A wireless network with internet access is available at the installation site. |
| ASM-2 | The site accepts that biometric data will be processed, and has obtained any consent required by local law. |
| ASM-3 | The number of enrolled users at a single site will not exceed a few thousand. |
| ASM-4 | Attendees present themselves one at a time. The system is not required to handle a crowd. |
| ASM-5 | Attendees are cooperative — they are trying to be recognized, not trying to avoid it. |
| ASM-6 | Mains power is available and reasonably stable. |

---

## 3. Specific Requirements

### 3.1 External Interface Requirements

#### 3.1.1 User Interfaces

**UI-1.** The device display shall at all times show which of the following states the system is in: ready, processing, access granted, access denied, or service unavailable.

**UI-2.** State shall be distinguishable by color as well as by text, so that the state is readable at a glance from a short distance.

**UI-3.** On a successful identification the display shall show the identified person's name.

**UI-4.** On a failed identification the display shall show a message indicating the person was not recognized. It shall not reveal any information about enrolled users.

**UI-5.** Result screens shall return to the ready state automatically. No user action shall be required to reset the device.

**UI-6.** The administration interface shall allow an administrator to complete user enrollment without technical assistance.

#### 3.1.2 Hardware Interfaces

**HI-1.** The system shall capture still images from the camera module at a resolution sufficient for the face recognition process to operate within the accuracy targets in section 3.4.

**HI-2.** The system shall read the UID of an ISO/IEC 14443 Type A card presented within the reader's normal operating range.

**HI-3.** The system shall drive the door latch to an unlocked position and return it to a locked position.

**HI-4.** The latch shall be in the locked position whenever the system is not actively granting access, including after a power failure, a reset, or a software fault.

#### 3.1.3 Communication Interfaces

**CI-1.** All communication between the door device and the server shall be encrypted in transit.

**CI-2.** The server shall authenticate each door device before accepting any data from it. Data from an unrecognized device shall be rejected.

**CI-3.** The device shall report its liveness to the server periodically so that outages are detectable.

**CI-4.** The device shall obtain its operational configuration from the server, so that behavior can be adjusted without reprogramming the device.

**CI-5.** The device shall maintain accurate time, synchronized from the network when available, so that events recorded while offline carry correct timestamps.

---

### 3.2 Functional Requirements

#### 3.2.1 Face Attendance

**FR-1.** The device shall continuously monitor the camera for the presence of a face while in the ready state.

**FR-2.** The device shall only initiate an identification attempt when a face has been present continuously for a short interval. It shall not initiate an attempt on a person merely passing by.

**FR-3.** When the identification attempt is initiated, the device shall capture the region of the image containing the face and transmit it to the server.

**FR-4.** The server shall determine whether the received face corresponds to an enrolled, active user.

**FR-5.** The server shall return to the device a decision indicating whether access is granted, and if so, the identity of the person.

**FR-6.** Where more than one face is present, the system shall process the most prominent face and ignore the others.

**FR-7.** The device shall not attempt to determine identity itself. All identity decisions shall be made by the server.

#### 3.2.2 Card Attendance

**FR-8.** The device shall monitor for the presence of an RFID card while in the ready state, concurrently with face monitoring. A person shall be able to use either method at any time without switching modes.

**FR-9.** On detecting a card, the device shall read its UID and transmit it to the server.

**FR-10.** The device shall not evaluate whether a card UID is authorized. That decision shall be made by the server, so that a card can be revoked centrally and take effect immediately.

**FR-11.** The server shall grant access only if the UID belongs to an enrolled user whose account is active.

#### 3.2.3 Attendance Recording

**FR-12.** The system shall record every identification attempt, whether successful or not, together with the time it occurred, the device where it occurred, the method used, and the outcome.

**FR-13.** A repeat presentation by the same person within a configurable cooldown period shall not create an additional attendance record.

**FR-14.** A repeat presentation within the cooldown period shall nevertheless grant access. Access shall not be denied on the grounds that attendance has already been recorded.

**FR-15.** Attendance records shall carry the time the event occurred at the device, which may differ from the time the server received it.

#### 3.2.4 Access Control

**FR-16.** On a granted decision, the device shall unlock the latch, hold it unlocked for a configurable period, and then relock it.

**FR-17.** On a denied decision, the latch shall not move.

**FR-18.** If the device does not receive a decision from the server within a defined timeout, it shall treat the outcome as denied and shall not unlock.

#### 3.2.5 Offline Operation

**FR-19.** When the network is unavailable, the device shall remain operational and shall inform the user of the degraded state.

**FR-20.** The device shall store attendance events that could not be transmitted, and shall transmit them once connectivity is restored.

**FR-21.** Stored events shall retain the time at which they originally occurred.

**FR-22.** Events shall be removed from local storage only after the server has confirmed receipt.

**FR-23.** The system shall provide a configurable option to grant card-based access while offline, using authorization data cached from the last successful synchronization. This option shall be disabled by default.

**FR-24.** Face-based access shall not be granted while offline, since identification cannot be performed on the device.

**FR-25.** If local storage for offline events becomes full, the device shall retain the oldest events and inform the user that new events cannot be recorded.

#### 3.2.6 Enrollment and User Management

**FR-26.** An administrator shall be able to register a new user with a name and an organizational identifier.

**FR-27.** Enrollment shall accept several images of the user's face, so that the stored representation is not dependent on a single lighting condition or pose.

**FR-28.** The system shall reject an enrollment image in which no face can be found, and shall tell the administrator why.

**FR-29.** An administrator shall be able to assign an RFID card to a user, change it, and revoke it.

**FR-30.** An administrator shall be able to deactivate a user. A deactivated user shall be denied access by both methods, immediately, without any action at the device.

**FR-31.** An administrator shall be able to permanently delete a user together with all of their personal data.

#### 3.2.7 Reporting and Monitoring

**FR-32.** An administrator shall be able to view attendance records filtered by user and by date range.

**FR-33.** An administrator shall be able to export attendance records in a format suitable for use in a spreadsheet.

**FR-34.** An administrator shall be able to see, for each installed device, when it last communicated with the server.

**FR-35.** The system shall record failed identification attempts and make them visible to administrators, so that repeated unauthorized attempts can be noticed.

---

### 3.3 Data Requirements

This section states what information the system must hold, not how it is stored.

**DR-1.** For each enrolled person the system shall hold: their name, an organizational identifier, their face representation, an optional card identifier, and whether their account is active.

**DR-2.** The face representation shall be stored in a form derived from the enrollment images. **Original enrollment images shall not be retained after the representation has been derived.**

**DR-3.** The stored face representation shall be associated with the version of the recognition process that produced it, so that representations can be regenerated if that process changes.

**DR-4.** For each attendance event the system shall hold: which person (where identified), which device, which method, the outcome, the confidence of the match where applicable, the time the event occurred, and the time it was received.

**DR-5.** For each installed device the system shall hold: an identifier, its physical location, its authentication credential, and the time it was last seen.

**DR-6.** A card identifier shall be assigned to at most one person at any time.

**DR-7.** Attendance records shall be retained for a configurable period, after which they may be archived or purged in accordance with site policy.

---

### 3.4 Performance Requirements

**PR-1.** The interval from a person presenting their face to the door beginning to unlock shall not exceed **2 seconds** under normal network conditions.

**PR-2.** The interval from a card being tapped to the door beginning to unlock shall not exceed **1 second**.

**PR-3.** The device shall evaluate camera frames for the presence of a face at a rate of at least **5 frames per second**.

**PR-4.** The server shall complete the recognition process for a single face within **500 milliseconds**.

**PR-5.** The server shall support at least **10 door devices** submitting events concurrently without exceeding PR-4.

**PR-6.** The device shall resume the ready state within **1 second** of completing a result display.

---

### 3.5 Accuracy Requirements

**AR-1.** The false acceptance rate shall not exceed **0.1%**. A false acceptance is a security failure and is the more serious of the two error types.

**AR-2.** The false rejection rate should not exceed **5%**. A false rejection is an inconvenience; the person may retry or use their card.

**AR-3.** The decision threshold that governs the trade-off between AR-1 and AR-2 shall be configurable without reprogramming the device or redeploying the server.

**AR-4.** The accuracy targets apply under the lighting conditions present at the installation site. Acceptance testing shall be performed under those conditions, not under laboratory lighting.

**AR-5.** The system shall record the confidence of each successful match, so that threshold tuning can be based on real operating data.

---

### 3.6 Safety and Security Requirements

**SR-1.** Face images and face representations shall be treated as sensitive personal data throughout the system.

**SR-2.** Face images shall never be transmitted or stored unencrypted.

**SR-3.** Face images buffered on the device shall be erased as soon as they have been successfully transmitted.

**SR-4.** The administration interface shall require authentication. Only authenticated administrators shall be able to view or modify user data or attendance records.

**SR-5.** A person's complete personal data shall be removable from the system on request, in support of data protection obligations.

**SR-6.** The door latch shall fail to the locked state. No fault condition — power loss, software crash, network failure, or peripheral failure — shall leave the door unlocked.

**SR-7.** The system does not detect presentation attacks. **A photograph of an enrolled person may be sufficient to obtain access.** This is a known limitation of this release and shall be documented for anyone deploying the system. Sites requiring protection against this shall not rely on face recognition as the sole access control.

**SR-8.** Denial messages shall not disclose whether a presented face or card is close to any enrolled record.

---

### 3.7 Reliability and Availability Requirements

**RR-1.** The device shall recover automatically from a loss of network connectivity, a server timeout, or a peripheral communication failure, without manual intervention.

**RR-2.** The device shall detect and recover from a software hang without manual intervention.

**RR-3.** After any restart, the device shall return to a known safe state with the latch locked.

**RR-4.** No attendance event that has been accepted by the device shall be lost as a result of a network outage or a device restart.

**RR-5.** The device shall be able to operate offline for at least **24 hours** without loss of recorded card events.

---

### 3.8 Maintainability and Configurability Requirements

**MR-1.** The following shall be configurable from the server without reprogramming the device: the recognition decision threshold, the door unlock duration, the attendance cooldown period, the server request timeout, and whether offline card access is permitted.

**MR-2.** The recognition model on the server shall be replaceable without changing the device firmware.

**MR-3.** The system shall log sufficient diagnostic information for a maintainer to determine the cause of a failed identification without physical access to the device.

---

### 3.9 Usability Requirements

**UR-1.** An attendee shall be able to use the system correctly on their first attempt without instruction.

**UR-2.** The device shall indicate a result within the time limits of PR-1 and PR-2, or shall indicate that it is working, so that the user is never left uncertain whether the device has responded.

**UR-3.** An administrator shall be able to enroll a new user in under three minutes.

---

## 4. Verification

Each requirement shall be verifiable. The following table shows how each category will be confirmed.

| Requirement group | Verification method |
|---|---|
| Functional (FR) | Functional testing against each requirement, on assembled hardware |
| Performance (PR) | Timed measurement on the target hardware under representative load |
| Accuracy (AR) | Statistical testing with a test population under site lighting conditions |
| Security (SR) | Inspection, network capture analysis, and penetration testing of the administration interface |
| Reliability (RR) | Fault injection — network disconnection, power cycling, peripheral disconnection |
| Usability (UR) | Observation of untrained users completing the task |

Accuracy requirements in particular shall not be considered met on the basis of published model benchmarks. They shall be measured on this system, with this camera, at the installation site.

---

## 5. Open Issues

These must be resolved before the design is finalized. Each has been raised because it materially affects whether the requirements above can be met.

| ID | Issue | Why it matters |
|---|---|---|
| OI-1 | The camera specified in CON-3 has limited low-light performance. | May prevent AR-1 and AR-2 being met at an entrance in evening conditions. Requires early testing; may require supplementary illumination or a different camera. |
| OI-2 | Available bandwidth between the device and the network module has not been measured. | Directly determines whether PR-1 can be met when transmitting an image. |
| OI-3 | Available flash for offline buffering has not been quantified against CON-9. | Determines whether RR-5 is achievable, and whether face events can be buffered at all. |
| OI-4 | The retention period for attendance records (DR-7) has not been set. | Depends on site policy and applicable data protection law. |
| OI-5 | Whether the site requires protection against presentation attacks (SR-7). | If it does, the current scope is insufficient and liveness detection must be added to scope. |

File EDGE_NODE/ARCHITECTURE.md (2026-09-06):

# Architecture

Design decisions and internal mechanics for this project. For build/run
instructions see [README.md](README.md); for the dated bring-up history
see [WORKLOG.md](WORKLOG.md).

## 1. System Overview

```
[OV7670 camera] --DVP(PCLK/HREF/VSYNC)--> [SmartDMA coprocessor] --frame buffer-->
  --> [AI inference: CPU/CMSIS-NN or Neutron NPU] --> [LCD status text, bit-bang GPIO]
                                                    \-> [SD snapshot (LPSPI1), only on face detection]
```

Camera capture and AI inference run **sequentially, not in parallel** (see
§3) on core0 only — this is a single-core application despite the MCXN947
being dual-core (core1 never boots, see §4). Two coprocessors do the heavy
lifting off the main Cortex-M33: SmartDMA assembles camera frames without
CPU involvement, and the Neutron NPU (default backend) runs the
model's convolution-heavy layers without CPU involvement.

## 2. Components

### Camera capture — `source/camera/camera_capture.c`

- **Responsibility:** drive the OV7670 over SCCB (config) and DVP
  (PCLK/HREF/VSYNC/D0-D7, pixel data), using SmartDMA to assemble frames.
- **Why SmartDMA, not a software loop:** DVP is a parallel interface with
  camera-driven timing (not synchronized to the CPU); at 320x240@30fps
  (~2.3 MB/s) a software GPIO-polling loop can't keep up. SmartDMA is a
  separate programmable coprocessor that runs its own microcode
  understanding DVP timing directly, assembling frames in parallel with
  whatever the main core is doing.
- **Key APIs:**
  ```c
  SMARTDMA_InstallFirmware(SMARTDMA_CAMERA_MEM_ADDR, s_smartdmaCameraFirmware, ...);
  SMARTDMA_InstallCallback(CAMERA_CAPTURE_CompleteCallback, NULL);
  NVIC_EnableIRQ(SMARTDMA_IRQn);
  SMARTDMA_Boot(kSMARTDMA_CameraWholeFrameQVGA, &smartdmaParam, 0x2);
  ```
  Completion fires `SMARTDMA_IRQn` → `CAMERA_CAPTURE_CompleteCallback()` →
  sets a flag the main loop polls. Main CPU never touches pixel-level
  timing.
- **Gotcha:** the first frame captured immediately after
  `CAMERA_CAPTURE_Reinit()` is not yet synced and must be discarded (see
  WORKLOG.md for the bug this caused: every frame reading back flat/zero
  in the AI-integrated build).

### AI inference — `source/ai/model_runner.h` (+ two backends)

- **Responsibility:** run the FOMO face-detection model on a captured
  frame; identical API (`model_runner.h`) for both backends, selected at
  build time via `AI_MODEL_USE_NPU`.
- **CPU backend** (`model_runner.cpp`): Edge Impulse's own
  `ei_run_classifier()`, non-EON TFLite Micro interpreter.
- **NPU backend** (`model_runner_npu.cpp`): bypasses Edge Impulse's SDK
  entirely (its `ei_run_classifier()` has no hook for registering a custom
  op) and talks to TensorFlow Lite Micro directly:
  ```cpp
  static tflite::MicroMutableOpResolver<3> s_opResolver;
  s_opResolver.AddSlice();
  s_opResolver.AddSoftmax();
  s_opResolver.AddCustom(tflite::GetString_NEUTRON_GRAPH(), tflite::Register_NEUTRON_GRAPH());
  tflite::MicroInterpreter interpreter(model, s_opResolver, tensorArena, arenaSize);
  interpreter.AllocateTensors();
  interpreter.Invoke();  // NEUTRON_GRAPH portion runs on the NPU
  ```
  `neutronInit()` (real hardware init) is called lazily, internally, by the
  `NEUTRON_GRAPH` kernel on its first `Prepare()` — no manual NPU-start
  call needed anywhere in application code.
- **Model conversion for NPU:** the `.tflite` Edge Impulse Studio exports
  must be run through NXP's `neutron_converter` CLI (`eiq_neutron_sdk`
  package) before use:
  ```bash
  neutron_converter --input model.tflite --target mcxn94x --output model_npu.tflite
  ```
  This collapses supported layers (conv/pool/add/...) into one custom
  `NEUTRON_GRAPH` op; unsupported layers (`Slice`, `Softmax` for this
  model) stay as regular TFLM ops. Current model: 31/33 ops folded into
  the NPU op.
- **Timing:** measured by hand via the Cortex-M33 DWT cycle counter
  (`DWT->CYCCNT` → microseconds via `SystemCoreClock`), not Edge Impulse's
  own `ei_result.timing` field — that field reads `0` on this
  SDK/porting combination (`ei_read_timer_us()` is hard-coded to return 0
  in the bare-metal clib porting layer).
- **Gotcha:** quantization for this model reduces to `pixel_value - 128`
  (scale ≈ 1/255, zero_point = -128) — no runtime division/multiplication
  needed, convenient on an MCU without a FPU-heavy quantization path.

### Display — `source/display/lcd_spi_hw.c` (default) / `lcd_bitbang.c`, `lcd_flexio_mculcd.c` (abandoned J8 path)

- **Responsibility:** draw fixed text status lines (`FACE: 1`/`0`,
  `CAPTURE: 1`/`0`) via hardware LPSPI1 on the Arduino header (previously
  bit-banged 8080 parallel, then bit-banged SPI, before settling on
  hardware SPI shared with the microSD/touch bus - see WORKLOG.md).
- **Key APIs:** `LCD_Init()`, `LCD_InitPanel()` (generic MIPI-DCS init
  sequence, works across ILI9481/ILI9486/HX8357/ST7796-family panels),
  `DEMO_DrawStatusLine()` in `main.c`.

### Shared SPI bus — `source/spi1_bus.c` (LCD + microSD + touch)

- **Responsibility:** own the single hardware LPSPI1 peripheral all three
  Arduino-header SPI devices ride (see `source/spi1_bus.h`'s file
  comment for the full sharing contract). Only the microSD slot uses the
  peripheral's real hardware chip-select (PCS0/D10 - `SDSPI_Init()` needs
  runtime PCS-polarity flipping that only works through real PCS
  hardware); the LCD and touch controller each use a plain GPIO pin for
  CS instead, transferring via `kLPSPI_MasterPcs1` (a PCS channel never
  muxed to a physical pin on this board, so it's a "don't care" value).
- **Key APIs:** `SPI1_BUS_Init()` (idempotent - safe to call from every
  device driver's own init), `SPI1_BUS_SetBaudRate()` (must be called
  right before every transaction, not just once - see below),
  `SPI1_BUS_TransferBlocking()`.
- **Why per-transaction baud-rate reclaiming is required:** the three
  devices need different SPI speeds (SD: 400kHz during card
  identification, then up to `SD_SPI_OPERATING_BAUDRATE`; LCD/touch: their
  own conservative starting baud rates), and `main.c`'s loop interleaves
  LCD draws with SD snapshot writes every frame. `sd_spi_disk.c`'s
  `disk_read()`/`disk_write()` and `lcd_spi_hw.c`'s
  `LCD_BeginTransaction()`/`touch_xpt2046.c`'s `TOUCH_ReadChannel()` each
  call `SPI1_BUS_SetBaudRate()` immediately before their own transfer, so
  whichever rate the bus was left at by the last device to use it doesn't
  matter. `SDSPI_Init()` itself is the one exception that doesn't need
  this: `middleware/sdmmc/sdspi/fsl_sdspi.c` already re-asserts the
  400kHz identification speed unconditionally at its own start.
- **UNTESTED on real hardware** - see WORKLOG.md and README.md's Known
  Limitations. This is the newest and highest-risk part of the LCD/SD/
  touch integration.

### SD card snapshot — `source/storage/sd_spi_disk.c` + `snapshot.c`

- **Responsibility:** on face detection, draw a box into the camera frame
  buffer (`bbox_overlay.c`, shared with the abandoned live-image LCD path)
  and save it as a BMP to the microSD card on the TFT panel (Arduino
  D10..D13, shared SPI bus - see above), rate-limited to 1 capture/sec via
  the DWT cycle counter.
- **Why the SDK's own SD-over-SPI FatFs glue isn't used:**
  `middleware/fatfs/source/fsl_sdspi_disk/` is hardcoded to the DSPI
  peripheral (`fsl_dspi.h`), which doesn't exist on the MCXN947 (LPSPI-
  family chip) — `#include`ing it at all triggers a `#error` from inside
  `fsl_sdspi_disk.h` itself. `sd_spi_disk.c` reimplements the same 5
  `diskio.h` functions (`disk_initialize/status/read/write/ioctl`) against
  `fsl_sdspi.h` (the SDK's actual protocol layer, chip-agnostic) with an
  `sdspi_host_t` driving `LPSPI1` directly instead.
- **Why FatFs core (`ff.c`) is pulled directly in `CMakeLists.txt`
  instead of via `CONFIG_MCUX_COMPONENT_middleware.fatfs`:** that Kconfig
  component always bundles `middleware/fatfs/source/diskio.c` alongside
  `ff.c`, which would collide at link time with `sd_spi_disk.c`'s own
  `disk_*` functions. Same reasoning for pulling `fsl_sdspi.c` directly
  instead of via `CONFIG_MCUX_COMPONENT_middleware.sdmmc.sdspi` - that
  option also auto-selects `middleware.sdmmc.common`, which doesn't even
  compile without a host-controller (SDHC/USDHC) component selected
  (`fsl_sdmmc_common.h` unconditionally `#include`s `fsl_sdmmc_host.h`) -
  unnecessary anyway, since `fsl_sdspi.c` never calls into
  `fsl_sdmmc_common.c`.
- **RAM:** `ffconf.h` is hand-written (not Kconfig-generated) with
  `FF_FS_TINY=1` (shares one 512B sector buffer instead of giving every
  open `FIL` its own) and `FF_USE_LFN=0` (fixed 8.3 filenames,
  `FACEnnnn.BMP`) - `m_data` was already >90% used before this feature
  (see README.md), so every static byte here was deliberately fought for.
  The snapshot BMP itself needs **zero** extra frame-sized RAM: it's
  written straight out of the existing camera frame buffer with one
  `f_write()` call (top-down BMP row order matches the buffer's own
  layout; RGB565 needs no pixel-format conversion for a 16bpp BMP).
- **Confirmed on real hardware** (2026-08-25, after fixing 3 bugs found by
  live SWD debugging — see §5) — SD card mounts successfully
  (`Snapshot: SD card ready.`). Not yet separately confirmed: an actual
  face-triggered capture — see README.md's Known Limitations.

## 3. Key Design Decisions

| Decision | Alternative(s) considered | Why this way |
|---|---|---|
| Camera capture and AI inference run sequentially (`CAMERA_CAPTURE_Deinit()` before inference, `_Reinit()` after) | Run in parallel, both using `m_sramx` | Both need the same 96KB `m_sramx` RAM bank at the same time — parallel use silently corrupts SmartDMA's working state (camera stops firing frame-ready interrupts, no error logged). Sequential is slightly slower but inference already dominated total pipeline time, so no real throughput cost. |
| CPU-path tensor arena split across `m_sramx` (primary) + `m_data` (overflow) | Single pool in `m_data` only | Model doesn't fit in `m_data` alone; `m_sramx` looks unused in the linker map (SmartDMA firmware is loaded into it at runtime via a function call, not the static linker) but is only safe to reuse because capture is fully stopped first — see row above. |
| LCD shows text status only, not live image + bounding boxes | Live image + box overlay (the original design) | Bit-bang GPIO bus is too slow to push a full frame plus AI overlay per inference cycle at acceptable rate; text status is enough for the drowsiness/face-presence use case. `bbox_overlay.c/h` is reused by the SD snapshot feature (see below) - just never drawn to the LCD itself. |
| TFT driven via Arduino-header bit-bang, not J8 FlexIO | J8 FlexIO (NXP's hardware-accelerated path) | FlexIO wiring/init confirmed correct (a bit-bang diagnostic on the same J8 pins worked), but the FlexIO hardware-bus path itself produced black/white noise pixel data — unresolved bus-speed/signal-integrity issue. Bit-bang is slower but correct. |
| No USB video streaming | UVC webcam streaming, or a Mid/Overdrive DCDC time-multiplex workaround | Real hardware constraint, not fixable in software — see §4. A working time-multiplex prototype existed but added complexity not justified since the product only needs the LCD status line. |
| core1 never boots; its reserved RAM region is left untouched | Reuse core1's reserved RAM bank for the tensor arena, same reasoning as the `m_sramx` reuse above | Different failure mode from `m_sramx` — see §4. Tried once, wedged the board (silent hang on the very first `.bss` zero-init access), reverted. |

## 4. Known Constraints & Trade-offs

### SmartDMA / AI tensor-arena RAM collision

- **Constraint:** the CPU-path tensor arena and SmartDMA's camera firmware
  cannot occupy `m_sramx` (96KB) at the same time.
- **Root cause:** `SMARTDMA_CAMERA_MEM_ADDR` (`0x04000000`) is the start of
  `m_sramx`; the SDK's board linker script has no output section for it
  because SmartDMA firmware is loaded at runtime, not link time — making
  the bank look free when it isn't.
- **Impact:** capture must be stopped (`CAMERA_CAPTURE_Deinit()`) before
  inference and restarted after — see §3, row 1.

### core1's reserved RAM bank is unsafe to reuse, for a different reason than `m_sramx`

- **Constraint:** cannot reuse the SDK-reserved core1 RAM region
  (`0x2004E000`-`0x20068000`, 104KB) even though core1 never boots in this
  project.
- **Root cause:** on MCX-family (and most NXP multicore) parts, SRAM
  instances are partitioned into separate **power domains**. A domain tied
  to a core that's never released from reset can be left in its default
  low-power/array-off state — accessing it is a bus fault against
  unpowered RAM, not a data-corruption problem like `m_sramx`. Nothing in
  this project's boot code powers up that domain, because nothing here
  ever asks for core1's resources.
- **Impact:** the moment `Reset_Handler`'s `.bss` zero-init loop touched a
  symbol placed in that region, the board produced zero UART output ever
  again — not even the pre-camera/AI boot banner. Confirming actual
  electrical status would require the reference manual's SPC/CMC
  power-domain register detail, not just the linker script. **"Reserved
  for another core that never boots" is a weaker safety argument than
  "reserved for a coprocessor whose activity this firmware controls
  directly" (i.e. the `m_sramx` case above) — don't reuse a region just
  because the current build never references it.**

### USB High-Speed streaming vs. camera capture

- **Constraint:** the camera and USB Video Class streaming cannot run at
  the same time on this board.
- **Root cause:** the MCXN947's DCDC core regulator needs Mid voltage
  (~1.0V) for reliable SmartDMA camera capture, but the USB HS PHY's PLL
  needs Overdrive voltage (~1.2V) to lock — mutually exclusive voltage
  requirements. The board's single USB-C connector is hard-wired to the HS
  controller only (no accessible USB FS alternative — UM12018 §2.3), so
  there's no wiring-level workaround either.
  - **Genuine hardware limitation, not fixable in software** — timing/config
    issues can be fixed in code; a PLL that physically cannot lock below a
    given voltage cannot.
- **Impact:** a working time-multiplexed prototype (periodic Mid ↔
  Overdrive switching) produced low-frame-rate, choppy UVC video; set
  aside since the product doesn't need a USB video feed. Source kept at
  `source/usb/usb_video_camera.c/h` (`-DUSB_STREAM_DIAGNOSTIC_DISABLE=OFF`).

## 5. Debugging & Tooling Notes

### Plain `pyocd flash`/`reset`/`erase` is unreliable on this chip/probe/pyOCD combination

- **Symptom:** `pyocd flash -t mcxn947 <elf>` fails at the
  connection/init stage (never reaches the programming progress bar) with
  one of:
  - `Error while running debug sequence 'DebugPortStart' (core cm33_core0): SWD/JTAG communication failure (WAIT ACK)` or `(FAULT ACK)`
  - `Error while running debug sequence 'ResetCatchClear' (core cm33_core1): ... (FAULT ACK)` (pyOCD's default connect flow touches core1's debug-catch config even though this project only uses core0)
  - `Error while running debug sequence 'ResetSystem' (core cm33_core0): ... (FAULT ACK)`

  `DP IDR` (the most basic SWD register read) always succeeds (`0x6ba02477`)
  — the physical SWD link is fine. The failures are inside this chip's
  CMSIS-Pack-defined debug *sequences*, which need retry logic plain pyOCD
  doesn't have for this pack/probe pairing.
- **What doesn't help:** power-cycling, lowering SWD clock, different
  `--connect` modes, different USB cable/port.
- **Fix — use NXP's `spsdk`/`nxpdebugmbox` instead of relying on pyOCD's
  generic connect flow:**
  ```bash
  pip install spsdk   # provides the nxpdebugmbox CLI

  # 1. Unlock AHB/core access via the Debug Mailbox — must run immediately
  #    before every pyOCD flash/reset call, doesn't persist across a fresh connection
  nxpdebugmbox -i mcu-link cmd -f mcxn947 start-debug-session

  # 2. Flash with the broken debug sequences disabled
  pyocd flash -t mcxn947 \
    -O "pack.debug_sequences.disabled_sequences=ResetCatchSet:cm33_core1,ResetCatchClear:cm33_core1,ResetSystem:cm33_core0,ResetSystem:cm33_core1" \
    <path-to-elf>

  # 3. Disabling ResetSystem means step 2 won't reset into the new image — do it separately
  nxpdebugmbox -i mcu-link tool reset -f mcxn947 -h
  ```
  Mass-erase/recovery works directly, no extra flags:
  ```bash
  nxpdebugmbox -i mcu-link cmd -f mcxn947 erase
  ```
- **ISP mode (SW3 held + SW1) is a red herring for this problem** — it does
  enter ROM bootloader mode (error signature changes to
  `Invalid AP address (#0)`), but `nxpdebugmbox erase`/`start-debug-session`
  work fine without it. Note `nxpdebugmbox`'s `write-to-flash` does *not*
  work outside a specific device life-cycle state — use it only for
  `erase`/`start-debug-session`, then hand off to `pyocd flash` for actually
  programming.
- **Takeaway:** for MCX-family (and likely other LPC55xx-lineage) NXP
  parts, if pyOCD's CMSIS-Pack connect flow faults on `WAIT ACK`/`FAULT ACK`
  inside a chip-specific debug sequence (not a plain register read), reach
  for `spsdk`/`nxpdebugmbox` rather than varying pyOCD-level knobs.

### SD card init hung the whole boot, then never worked at all - three separate bugs, all found and fixed by live SWD register inspection on real hardware

**Symptom:** boot hung completely - confirmed on real hardware
(2026-08-25) - no serial output past `LCD: bit-bang GPIO on the Arduino
header`, survived repeated resets (deterministic: same code path, same
result, every time). CONFIRMED FIXED as of this entry - see the end of
this section for the working log output.

**Bug 1 - `LPSPI_MasterTransferBlocking()` has literally no timeout unless
`SPI_RETRY_TIMES` is defined:**
`drivers/lpflexcomm/lpspi/fsl_lpspi.c` polls TX/RX FIFO status flags in
loops shaped like:
```c
#if SPI_RETRY_TIMES
    waitTimes = SPI_RETRY_TIMES;
    while ((...) && (--waitTimes != 0U))
#else
    while (...)
#endif
    { }
```
repeated ~19 times through that file. Whether this ever times out depends
entirely on the `SPI_RETRY_TIMES` **preprocessor macro** being defined
with a nonzero value by *someone* - it is not a runtime parameter. The
obvious place to set it, `CONFIG_SPI_RETRY_TIMES`, is a real Kconfig
option - but it's declared inside `drivers/lpspi/Kconfig`, gated under
the plain `driver.lpspi` component, which is for MCX chips where LPSPI is
its own standalone IP block. This chip's LPSPI1 lives inside a
`LP_FLEXCOMM` interface instead, gated by the separate
`driver.lpflexcomm_lpspi` component (see §2's SD card snapshot entry for
why that's the right component here) - and `drivers/lpflexcomm/lpspi/
Kconfig` has no `SPI_RETRY_TIMES` option at all. With this board's
*correct* Kconfig component enabled, the macro is simply never defined
anywhere, `#if SPI_RETRY_TIMES` evaluates false (undefined == 0), and
every one of those ~19 loops compiled to an unconditional `while (...) {}`
- a real infinite loop if the condition it's waiting on never becomes
true. **Fix:** define it directly in `CMakeLists.txt`, bypassing Kconfig
(same pattern as this project's other Kconfig-gap workarounds):
```cmake
mcux_add_macro(CC "-DSPI_RETRY_TIMES=100000")
```

**Bug 2 - fixing bug 1 alone converted "infinite hang" into "hang so long
it's indistinguishable from infinite in practice":** after bug 1's fix,
the board *still* didn't visibly progress past SD init after several
minutes. Diagnosed by halting the core over SWD mid-hang
(`pyocd commander -c halt -c reg`) and reading it repeatedly - the PC
*was* moving (inside `LPSPI_CombineWriteData`/`LPSPI_MasterTransferBlocking`,
not frozen at one address), meaning the CPU was doing real, bounded work,
just an enormous amount of it. Reading LPSPI1's own registers directly
over SWD (`CR`@0x40093010, `SR`@0x40093014, `FSR`@0x4009305C,
`RDR`@0x40093074 - offsets from `devices/MCX/MCXN/periph/PERI_LPSPI.h`)
confirmed the peripheral itself was configured and completing real
transfers correctly (`CR.MEN=1`, transfers finishing, `TCR` frame size
correct) - **but every response byte read back as `RDR=0x00`, never the
`0xFF` idle-high value SD-over-SPI expects.** `middleware/sdmmc/sdspi/
fsl_sdspi.c`'s own retry constant (`SDSPI_TRANSFER_RETRY_TIMES`, hardcoded
`20000`, not `#ifndef`-guarded so not overridable via `-D`) is nested up
to 2-3 levels deep in `SDSPI_Init()`'s call graph (e.g.
`SDSPI_ApplicationSendOperationCondition()`'s outer poll calls
`SDSPI_SendCommand()` which itself calls `SDSPI_WaitReady()`, each with
its own 20000-retry budget) - when every single response byte is wrong,
*every* nested wait maxes out its own budget, multiplying instead of
adding: 20000 × 20000 in the worst case, at ~20us/byte (SD init's
mandatory 400kHz clock) - minutes to hours, not the few seconds any of
the individual bounded loops implies on its own.

**Fix** (`source/storage/sd_spi_disk.c`): rather than trying to patch
`fsl_sdspi.c`'s own retry constants (hardcoded, and this project avoids
editing vendored SDK files directly), `SDCARD_SPI_Exchange()` - the
`sdspi_host_t.exchange` callback, which `fsl_sdspi.c` calls for *every*
single SPI transaction and immediately propagates a failure from, no
retry - now tracks its own short (2 second) wall-clock deadline via the
DWT cycle counter, armed once per `SDSPI_Init()` attempt in
`SDCARD_SPI_Init()`. Once the deadline passes, every subsequent
`exchange()` call returns failure immediately without touching hardware,
which unwinds every one of `fsl_sdspi.c`'s nested retry loops in one shot
regardless of how large their own internal budgets are. This is what
actually bounds total `SNAPSHOT_Init()` time to ~2 seconds, not bug 1's
fix alone.

**After bugs 1+2**, boot no longer hung, but the card still never
communicated - `RDR` (LPSPI1's received-byte register) read a constant
`0x00` on every single poll, never the SD-over-SPI idle-high `0xFF`,
so `SDSPI_Init()` correctly (per the bug 2 fix) failed fast every time:
```
Snapshot: initializing SD card (LPSPI1, D10..D13)...
Snapshot: SD card init timed out after 2000ms (no valid response) - giving up.
Snapshot: no usable SD card on the shield's slot (D10..D13) - snapshots disabled.
```
Ruled out first: the card itself (mounted cleanly as FAT32 in this
laptop's own SD reader) and basic seating (card confirmed in the
shield's slot, shield confirmed fully seated in the Arduino header).

**Bug 3 - the TFT shield's SD slot has no pull-up on the DO (MISO) line,
and `BOARD_InitSdCardPins()` didn't add one either:** cheap SD shields
commonly omit this, assuming the host board provides it - this project's
pin setup was copied from the SDK's own LPSPI1 b2b loopback example,
which never needs one (it talks to another on-chip LPSPI instance wired
directly on the same board, not through a connector to 3rd-party
hardware). With nothing pulling DO toward a defined level when the card
isn't actively driving it, the input floated and happened to settle on a
stable `0x00` - electrically indistinguishable from a genuine short
purely from software.

**Diagnosis:** rather than guessing, tested directly - added this chip's
own weak internal pull-up (`kPORT_PullUp`) to just the SDI/DO pin
(`board_port/pin_mux.c`) as a live experiment: a floating line should
read differently once pulled toward a level; a truly shorted/driven-low
line wouldn't budge, since a weak internal pull can't override an active
driver. Rebuilt, reflashed - the very next boot:
```
Snapshot: initializing SD card (LPSPI1, D10..D13)...
Snapshot: SD card ready.
AI_MODEL_RunInference: total classifier time = 3879us (3ms)
Camera: frame #16 ready, 792 samples, pixel range 0x2965..0xD65B, avg=0x6426
```
Confirmed floating on the first try - the pull-up is now a permanent part
of `BOARD_InitSdCardPins()`, not a diagnostic-only change; it's genuinely
required for this shield on this board.

**Takeaways:**
- When adding a new peripheral driver from an NXP example, check whether
  that example's Kconfig component is the same one your actual chip/board
  needs - components with near-identical names (`driver.lpspi` vs.
  `driver.lpflexcomm_lpspi` here) can gate genuinely different Kconfig
  option sets, and a *silently-undefined* safety macro is a much worse
  failure mode than a build error would have been.
- A chain of individually-bounded retry loops is not itself bounded - if
  loop A (budget *m*) calls loop B (budget *n*) on every one of its own
  iterations, the real worst case is *m*×*n*, not *m*+*n* or
  max(*m*,*n*). Don't assume a "shouldn't take long" component's own
  internal timeout is a usable upper bound for code that calls it in a
  retry loop of your own.
- Live SWD register inspection (`pyocd commander -c halt -c reg -c
  "read32 <addr>" -c go`) settled in minutes what static code reading
  alone couldn't - "is the PC moving" (real work vs. frozen) and "what's
  actually in the peripheral's data register" (protocol-level vs.
  electrical-level problem) are both directly observable without needing
  the target to cooperate (print, breakpoint, etc), which matters exactly
  when the target *is* the thing that's stuck.
- "MCU reads garbage from an SPI slave" has (at least) two electrically
  distinct causes that look identical in software - a genuine short/wrong
  signal, or a legitimately floating/undriven line with nowhere for the
  logic level to be pulled toward. Toggling the MCU's own weak internal
  pull-up and re-testing is a cheap, fast, non-destructive way to tell
  them apart on real hardware before reaching for a multimeter.

## 6. References

- NXP UM12018 (FRDM-MCXN947 board user manual), §2.3 — USB connector wiring
- `neutron_converter` / `eiq_neutron_sdk` — NXP package index
- `spsdk` / `nxpdebugmbox` — NXP Debug Mailbox tooling

## 7. Dual-Core Task Architecture (RTOS build)

Everything in §1-§6 above describes the **legacy single-core build**
(core1 never boots). The dual-core build (`-DDUALCORE_RTOS=ON`, see
README.md) splits the same pipeline across both cores under FreeRTOS:
**core1** owns camera + LCD + SD (one task, `CameraLcdTask`), **core0**
owns AI inference only (one task, `AiInferenceTask`). They talk over
MCMGR mailbox-interrupt doorbells and a fixed shared-RAM region — no
RPMsg-Lite, no OS-level IPC framework.

### 7.1 Boot sequence

core1 has no SAU on this chip (always Non-Secure — see KNOWLEDGE.md §9),
so core0 must grant it GPIO access *before* releasing it, and must finish
the whole MCMGR handshake *before* touching any FreeRTOS API (both are
real bugs this project hit — see WORKLOG.md):

```mermaid
sequenceDiagram
    participant C0 as core0 (main_core0.c)
    participant GPIO as GPIO0 / GPIO1 (PCNS)
    participant C1 as core1 (main_core1.c)

    C0->>C0: MCMGR_Init(), BOARD_InitHardware()
    C0->>GPIO: Grant PCNS (Non-Secure access) for core1's LCD pins
    C0->>C1: copy core1's image into RAM
    C0->>C1: MCMGR_StartCore() - release core1
    activate C1
    C1->>C0: MCMGR_GetStartupData() - wait for core0's handshake
    C1->>C1: BOARD_InitHardware(), SPI1_BUS_CreateLock()
    C1->>C1: xTaskCreate(CameraLcdTask); vTaskStartScheduler()
    deactivate C1
    C0->>C0: xTaskCreate(AiInferenceTask); vTaskStartScheduler()
```

### 7.2 Per-core task flow

```mermaid
flowchart TD
    subgraph core1["core1 - CameraLcdTask"]
        A1[Init camera + LCD] --> A2{Frame ready?}
        A2 -- no --> A2
        A2 -- yes --> A3[Stop camera DMA - freeze frame buffer]
        A3 --> A4[Signal frame-ready to core0]
        A4 --> A5{Result within 100ms?}
        A5 -- yes --> A6[Draw box overlay + save snapshot]
        A5 -- no --> A7[Skip overlay/snapshot this frame]
        A6 --> A8[Push frame to LCD]
        A7 --> A8
        A8 --> A9[Resume camera DMA]
        A9 --> A2
    end

    subgraph core0["core0 - AiInferenceTask"]
        B1[Init AI model] --> B2[Block until doorbell]
        B2 --> B3[Read shared frame buffer]
        B3 --> B4[Run inference - ~4ms on the NPU]
        B4 --> B5[Write result to shared RAM]
        B5 --> B6[Signal result-ready to core1]
        B6 --> B2
    end

    A4 -.MCMGR doorbell.-> B2
    B6 -.MCMGR doorbell.-> A5
```

### 7.3 One frame, end to end

```mermaid
sequenceDiagram
    participant Cam as Camera (SmartDMA)
    participant C1 as core1: CameraLcdTask
    participant Shared as Shared RAM
    participant C0 as core0: AiInferenceTask
    participant LCD
    participant SD as SD card

    Cam-->>C1: frame-ready interrupt
    C1->>Cam: CAMERA_CAPTURE_Deinit() - stop DMA, freeze buffer
    C1->>C0: IPC_SignalFrameReady(seq)
    C0->>Shared: read frame buffer (safe - frozen)
    C0->>C0: AI_MODEL_RunInference()
    C0->>Shared: write ai_ipc_result_t
    C0->>C1: IPC_SignalResultReady(seq)
    alt face detected
        C1->>LCD: draw bounding box
        C1->>SD: save BMP snapshot (rate-limited, 1/sec)
    end
    C1->>LCD: push full frame
    C1->>Cam: CAMERA_CAPTURE_Reinit() - resume DMA
```

### 7.4 How data actually moves

Both cores physically share one fixed RAM region
(`source/shared/ipc_layout.h`, carved out of core0's `m_data` since a
153,600-byte QVGA frame doesn't fit in core1's own 104KB region at all).
Nothing is copied across cores — both sides read/write the exact same
physical bytes through fixed addresses; only a 16-bit sequence number
actually travels through the doorbell interrupt itself.

| Data | Written by | Read by | Only safe when |
|---|---|---|---|
| Camera frame buffer (`IPC_FRAME_BUFFER_ADDR`, 153,600B) | SmartDMA, via core1 | core0 (inference), core1 (LCD push) | Between core1's `CAMERA_CAPTURE_Deinit()` and `Reinit()` - DMA is stopped, buffer is frozen |
| AI result (`IPC_RESULT_ADDR`, `ai_ipc_result_t`) | core0, after inference | core1, after `IPC_SignalResultReady()` | Any time after the doorbell for that frame's sequence number |
| Sequence number | Both (via the doorbell payload) | Both | Used to detect a stale/late reply, not to move real data |

The AI result uses its **own** plain-data struct (`ai_ipc_result_t`), not
`model_runner.h`'s `ai_model_result_t` — that struct's label field is a
`const char *` into core0's own flash, meaningless as a value copied into
shared RAM for core1 to dereference. `ai_ipc_result_t` inlines the label
as a fixed byte array instead, so the whole struct is safe to read/write
as plain bytes from either core.
</content>

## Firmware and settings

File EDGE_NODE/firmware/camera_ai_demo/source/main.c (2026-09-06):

/*
 * main.c - Camera_AI_Test1
 *
 * Default build: OV7670 capture (SmartDMA, J9 header, 320x240 RGB565) ->
 * FOMO face-detection inference (model_runner.cpp or model_runner_npu.cpp)
 * -> LCD text status line ("FACE: 1"/"0"), no USB. See WORKLOG.md for why
 * Arduino-header bit-bang is the active default over J8/FlexIO.
 *
 * bbox_overlay.c/h was originally for drawing boxes on the live LCD image;
 * that was dropped in favor of plain text (too much data over the bit-bang
 * bus), but the helper is reused by the SD snapshot feature below.
 *
 * SD card snapshot on face detection (source/storage/snapshot.c): draws a
 * box into the camera frame buffer and saves it as a BMP to the TFT
 * shield's onboard microSD slot, rate-limited to 1 capture/sec. The LCD
 * never shows the box, only the saved file does.
 *
 * USB Video Class streaming (source/usb/) is ABANDONED - SmartDMA capture
 * and the USB HS PHY need mutually exclusive DCDC voltage levels on this
 * chip, no software fix possible. Still builds (opt-in via
 * USB_STREAM_DIAGNOSTIC_DISABLE=OFF), runs time-multiplexed - see
 * WORKLOG.md.
 */

#include <stdbool.h>
#include <string.h>
#include "app.h"
#include "board.h"
#include "camera_capture.h"
#include "ei_sramx_alloc.h"
#include "font5x7.h"
#include "fsl_common.h"
#include "fsl_debug_console.h"
#include "lcd_display.h"
#include "model_runner.h"
#include "snapshot.h"
#include "text_overlay.h"
#include "usb_video_camera.h"

#if !DEMO_LCD_CAMERA_PREVIEW
/* Fixed-width label + ": " + '1'/'0' for whether a face was detected this
 * frame. Unused in the raw camera-preview build. */
#define DEMO_STATUS_TEXT_SCALE 3U
#define DEMO_STATUS_LINE_X 8U
#define DEMO_STATUS_LINE_Y0 40U
#define DEMO_STATUS_LINE_GAP_PX 14U

static void DEMO_DrawStatusLine(uint16_t lineIndex, const char *paddedLabel, bool detected) {
  char text[16];
  size_t n = strlen(paddedLabel);

  memcpy(text, paddedLabel, n);
  text[n] = ':';
  text[n + 1U] = ' ';
  text[n + 2U] = detected ? '1' : '0';
  text[n + 3U] = '\0';

  uint16_t lineHeight = (uint16_t)((FONT5X7_HEIGHT * DEMO_STATUS_TEXT_SCALE) + DEMO_STATUS_LINE_GAP_PX);
  uint16_t y = (uint16_t)(DEMO_STATUS_LINE_Y0 + lineIndex * lineHeight);
  uint16_t fgColor = detected ? 0x07E0U /* green - detected this frame */ : 0x7BEFU /* mid gray - not detected */;

  TEXT_DrawString(DEMO_STATUS_LINE_X, y, text, fgColor, 0x0000U /* black background */, DEMO_STATUS_TEXT_SCALE);
}
#endif /* !DEMO_LCD_CAMERA_PREVIEW */

/* Fills the LCD with one solid color at startup, to clear old GRAM
 * content. Must use LCD_PushPixelsOpen()/LCD_EndWindow() in a loop, not
 * repeated LCD_PushPixels() calls - that closes the transfer (CS high)
 * every time, so only the first row would actually reach the panel. */
static void DEMO_ClearScreen(uint16_t color) {
  static uint16_t s_clearLine[DEMO_PANEL_WIDTH];
  for (uint16_t i = 0U; i < DEMO_PANEL_WIDTH; i++) {
    s_clearLine[i] = color;
  }
  LCD_SetWindow(0U, 0U, DEMO_PANEL_WIDTH - 1U, DEMO_PANEL_HEIGHT - 1U);
  for (uint16_t row = 0U; row < DEMO_PANEL_HEIGHT; row++) {
    LCD_PushPixelsOpen(s_clearLine, DEMO_PANEL_WIDTH);
  }
  LCD_EndWindow();
}

#if !DEMO_LCD_CAMERA_PREVIEW
/* Cheap "is the camera sending real data" check: min/max/avg over a
 * strided sample. A dead/disconnected sensor reads flat (min==max). */
static void CAMERA_CAPTURE_LogFrameSignature(uint32_t frameNumber,
                                             const uint16_t *frame) {
  const uint32_t pixelCount = (uint32_t)DEMO_BUFFER_WIDTH * DEMO_BUFFER_HEIGHT;
  const uint32_t stride = 97U; /* prime, avoids lining up with row width */
  uint16_t minPixel = 0xFFFFU;
  uint16_t maxPixel = 0x0000U;
  uint32_t sum = 0U;
  uint32_t samples = 0U;

  for (uint32_t i = 0; i < pixelCount; i += stride) {
    uint16_t p = frame[i];
    if (p < minPixel) {
      minPixel = p;
    }
    if (p > maxPixel) {
      maxPixel = p;
    }
    sum += p;
    samples++;
  }

  PRINTF("Camera: frame #%u ready, %u samples, pixel range 0x%04X..0x%04X, "
         "avg=0x%04X%s\r\n",
         frameNumber, samples, minPixel, maxPixel, (uint16_t)(sum / samples),
         (minPixel == maxPixel) ? " (flat - lens cap on, or no real image data)"
                                : "");
}
#endif /* !DEMO_LCD_CAMERA_PREVIEW */

#if !DEMO_USB_STREAM_DISABLE && !DEMO_LCD_CAMERA_PREVIEW
/* Everything below, down to DEMO_CaptureFramesAtMidVoltage(), only exists
 * for the abandoned USB-streaming path. */

/* Frames to capture at Mid voltage before switching to Overdrive/USB -
 * more than 1 so auto-exposure/gain can converge. */
#define DEMO_MID_VOLTAGE_WARMUP_FRAMES 10U

/* How long to stay at Overdrive/streaming before dropping back to Mid for
 * a fresh frame. Confirmed stable at 5000ms on real hardware. */
#define DEMO_OVERDRIVE_HOLD_MS 5000U

/* Capture DEMO_MID_VOLTAGE_WARMUP_FRAMES frames at Mid voltage, log the
 * last one, then stop SmartDMA. Caller must already be at DCDC Mid. */
static void DEMO_CaptureFramesAtMidVoltage(void) {
  uint16_t *frame = NULL;
  uint32_t frameNumber = 0U;
  uint32_t startCount = CAMERA_CAPTURE_GetFrameCount();

  while ((CAMERA_CAPTURE_GetFrameCount() - startCount) <
         DEMO_MID_VOLTAGE_WARMUP_FRAMES) {
    if (CAMERA_CAPTURE_IsFrameReady()) {
      CAMERA_CAPTURE_ClearFrameReady();
      frame = CAMERA_CAPTURE_GetFrameBuffer();
      frameNumber = CAMERA_CAPTURE_GetFrameCount();
    }
  }
  CAMERA_CAPTURE_LogFrameSignature(frameNumber, frame);
  PRINTF("Camera: capture stopped after frame #%u.\r\n", frameNumber);
  CAMERA_CAPTURE_Deinit();
}
#endif /* !DEMO_USB_STREAM_DISABLE && !DEMO_LCD_CAMERA_PREVIEW */

int main(void) {
  BOARD_InitHardware();

  PRINTF("\r\nCamera_AI_Test1 - FRDM-MCXN947\r\n");
  PRINTF("Camera: OV7670 on J9 SmartDMA/Camera header\r\n");

#if DEMO_LCD_CAMERA_PREVIEW
  /* Lens-focus diagnostic (-DLCD_CAMERA_PREVIEW=ON): no AI, no status
   * text - raw camera feed pushed straight to the LCD as fast as frames
   * arrive, for focusing by eye. Camera resolution matches the panel 1:1.
   *
   * TEARING FIX (see WORKLOG.md): once the camera clock was fixed to run
   * at its real ~30fps, it became faster than the ~57ms LCD push and
   * could overwrite the frame buffer mid-push, tearing the image. Fixed
   * like the AI loop below: stop SmartDMA before reading the buffer,
   * restart after, discard the first frame post-restart (SmartDMA needs
   * one cycle to resync with the sensor). Real double-buffering isn't
   * RAM-feasible here (a second frame buffer doesn't fit in either bank). */
  PRINTF("Display: raw camera preview on LCD, no AI (LCD_CAMERA_PREVIEW=ON) "
         "- for focusing the lens\r\n\r\n");

  CAMERA_CAPTURE_Init();
  LCD_Init();
  DEMO_ClearScreen(0x0000U);

  /* DWT cycle counter for a measured fps readout once/sec. */
  CoreDebug->DEMCR |= CoreDebug_DEMCR_TRCENA_Msk;
  DWT->CTRL |= DWT_CTRL_CYCCNTENA_Msk;
  uint32_t fpsFrameCount = 0U;
  uint32_t fpsWindowStartCycle = DWT->CYCCNT;

  /* Also tracks time spent waiting for the next frame, to see how much of
   * the frame period is the LCD push vs. waiting on the camera. */
  uint32_t diagWaitCycles = 0U;
  uint32_t diagWaitStartCycle = DWT->CYCCNT;

  /* Set right after CAMERA_CAPTURE_Reinit(), cleared once the next frame
   * is consumed - see the tearing-fix comment above. */
  bool skipNextFrame = false;

  while (1) {
    if (CAMERA_CAPTURE_IsFrameReady()) {
      diagWaitCycles += (DWT->CYCCNT - diagWaitStartCycle);
      CAMERA_CAPTURE_ClearFrameReady();

      if (skipNextFrame) {
        skipNextFrame = false;
        diagWaitStartCycle = DWT->CYCCNT;
        continue;
      }

      /* Stop SmartDMA before reading the frame buffer, restart after -
       * tearing fix, see above. */
      CAMERA_CAPTURE_Deinit();
      LCD_DrawImage(0U, 0U, DEMO_BUFFER_WIDTH, DEMO_BUFFER_HEIGHT,
                    CAMERA_CAPTURE_GetFrameBuffer());
      CAMERA_CAPTURE_Reinit();
      skipNextFrame = true;

      fpsFrameCount++;
      diagWaitStartCycle = DWT->CYCCNT;

      /* (int32_t) cast makes this wrap-safe across DWT->CYCCNT rollover. */
      if ((int32_t)(DWT->CYCCNT - fpsWindowStartCycle) >= (int32_t)SystemCoreClock) {
        PRINTF("LCD preview: %u fps (wait-for-frame=%uus/frame avg)\r\n",
               fpsFrameCount,
               (unsigned)(diagWaitCycles / (SystemCoreClock / 1000000U) /
                          (fpsFrameCount == 0U ? 1U : fpsFrameCount)));
        fpsFrameCount = 0U;
        diagWaitCycles = 0U;
        fpsWindowStartCycle = DWT->CYCCNT;
      }
    }
  }
#else

#if DEMO_USB_STREAM_DISABLE
#if DEMO_LCD_ARDUINO_HEADER
  PRINTF("Display: Arduino-header LCD status text (camera + AI hook)\r\n\r\n");
#else
  PRINTF("Display: J8 LCD status text (camera + AI hook)\r\n\r\n");
#endif
#else
  PRINTF("Display: USB Video Class (UVC) webcam over USB High-Speed "
         "(abandoned path, time-multiplexed - see WORKLOG.md)\r\n\r\n");
#endif

  CAMERA_CAPTURE_Init();
  AI_MODEL_Init();

#if DEMO_USB_STREAM_DISABLE
  /* Default build: camera + AI loop, continuous, DCDC stays at Mid the
   * whole time. LCD shows fixed text status lines - see file-level
   * comment above. */
  LCD_Init();
  DEMO_ClearScreen(0x0000U);

  /* SD card snapshot-on-face-detection - see source/storage/snapshot.c.
   * Safe to call with no card present (SNAPSHOT_OnFrame() just no-ops). */
  SNAPSHOT_Init();

#if !DEMO_AI_MODEL_USE_NPU
  /* CPU-path scratch pool - overflow area for ei_sramx_alloc.c once the
   * primary 96KB m_sramx pool is exhausted. Must alone be big enough for
   * the whole tensor arena (currently 112,460 bytes): a single allocation
   * can't span m_sramx and m_data, they're non-contiguous banks. Only
   * used by the CPU/CMSIS-NN build - the NPU build has its own static
   * arena instead. See model_runner_npu.cpp for the matching NPU budget. */
  static uint8_t s_aiScratchPool[120U * 1024U] __attribute__((aligned(16)));
  EI_SRAMX_SetOverflowPool(s_aiScratchPool, sizeof(s_aiScratchPool));
#endif /* !DEMO_AI_MODEL_USE_NPU */

  /* Set right after CAMERA_CAPTURE_Reinit(), cleared once the next frame
   * is consumed - SmartDMA needs one cycle to resync with the sensor
   * after a fresh Reinit(), so the very next frame isn't trustworthy. */
  bool skipNextFrame = false;

  while (1) {
    if (CAMERA_CAPTURE_IsFrameReady()) {
      CAMERA_CAPTURE_ClearFrameReady();

      if (skipNextFrame) {
        skipNextFrame = false;
        continue;
      }

      uint16_t *frame = CAMERA_CAPTURE_GetFrameBuffer();
      uint32_t frameNumber = CAMERA_CAPTURE_GetFrameCount();

      /* Every 15th frame (~2x/sec at 30fps) so the log stays readable. */
      if ((frameNumber % 15U) == 1U) {
        CAMERA_CAPTURE_LogFrameSignature(frameNumber, frame);
      }

      /* Stop SmartDMA before inference: SmartDMA's own working RAM
       * (0x04000000) is the same bank as the AI tensor arena - leaving it
       * running while the arena is used corrupts SmartDMA's state (see
       * WORKLOG.md). */
      CAMERA_CAPTURE_Deinit();

      ai_model_result_t aiResult;
      AI_MODEL_RunInference(frame, DEMO_BUFFER_WIDTH, DEMO_BUFFER_HEIGHT,
                            &aiResult);

      /* Still before Reinit(): draws into/reads `frame` directly, so must
       * run while the buffer is stable. Internally rate-limited to at
       * most 1 capture/sec - a no-op most frames. */
      SNAPSHOT_OnFrame(frame, DEMO_BUFFER_WIDTH, DEMO_BUFFER_HEIGHT,
                       &aiResult, AI_MODEL_GetInputWidth(), AI_MODEL_GetInputHeight());

      CAMERA_CAPTURE_Reinit();
      skipNextFrame = true;

      bool sawFace = false;
      if (aiResult.valid) {
        for (uint32_t i = 0; i < aiResult.boxCount; i++) {
          const ai_bbox_t *box = &aiResult.boxes[i];
          if (strcmp(box->label, "face") == 0) {
            sawFace = true;
          }
          /* debug_console_lite may not support %f, so print score as a
           * percentage integer. */
          PRINTF("AI result: box[%u] label=%s x=%u y=%u w=%u h=%u score=%d%%\r\n",
                 i, box->label, box->x, box->y, box->width, box->height,
                 (int)(box->score * 100.0f));
        }
      }

      DEMO_DrawStatusLine(0U, "FACE      ", sawFace);

      /* Stays lit for the same window SNAPSHOT_OnFrame() rate-limits
       * captures to, so it clears itself as a new capture becomes
       * possible again. */
      DEMO_DrawStatusLine(1U, "CAPTURE   ", SNAPSHOT_IsNoticeActive());
    }
  }
#else
  /* USB streaming build: time-multiplexed. Mid-voltage capture first -
   * wait for settled frames, then stop SmartDMA (capture and USB HS can't
   * run at the same time on this chip). */
  DEMO_CaptureFramesAtMidVoltage();
  PRINTF("Camera: switching to Overdrive for USB.\r\n");

  ai_model_result_t aiResult;
  AI_MODEL_RunInference(CAMERA_CAPTURE_GetFrameBuffer(), DEMO_BUFFER_WIDTH,
                        DEMO_BUFFER_HEIGHT, &aiResult);
  if (aiResult.valid) {
    for (uint32_t i = 0; i < aiResult.boxCount; i++) {
      const ai_bbox_t *box = &aiResult.boxes[i];
      /* debug_console_lite may not support %f, so print score as a
       * percentage integer. */
      PRINTF("AI result: box[%u] label=%s x=%u y=%u w=%u h=%u score=%d%%\r\n",
             i, box->label, box->x, box->y, box->width, box->height,
             (int)(box->score * 100.0f));
    }
  }

  /* Full PHY/PLL bring-up + enumeration runs exactly ONCE here - the
   * periodic refresh loop below only calls the lighter regulator helpers. */
  USB_DeviceClockInit();
  USB_VideoCamera_Init();

  while (1) {
    USB_VideoCamera_Task();

    /* PERIODIC REFRESH - see DEMO_OVERDRIVE_HOLD_MS above. */
    SDK_DelayAtLeastUs(DEMO_OVERDRIVE_HOLD_MS * 1000U,
                       SDK_DEVICE_MAXIMUM_CPU_CLOCK_FREQUENCY);

    PRINTF("Camera: refreshing - dropping to Mid voltage to recapture.\r\n");
    BOARD_SetRegulatorsMidVoltage();
    CAMERA_CAPTURE_Reinit();
    DEMO_CaptureFramesAtMidVoltage();
    BOARD_SetRegulatorsOverdriveVoltage();
    PRINTF("Camera: back to Overdrive, streaming the new frame.\r\n");
  }
#endif
#endif /* DEMO_LCD_CAMERA_PREVIEW */
}

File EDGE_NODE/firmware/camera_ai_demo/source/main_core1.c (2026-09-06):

/*
 * main_core1.c - Camera_AI_Test1 dual-core RTOS migration (see WORKLOG.md).
 *
 * This core owns camera capture, LCD push, AI overlay drawing, and SD
 * snapshot - all in one task (CameraLcdTask). Splitting capture/push into
 * separate tasks would reintroduce a single-buffer race this project
 * already fixed once (see ARCHITECTURE.md).
 *
 * Real AI results come from core0 over a frame-ready/result-ready
 * doorbell round trip (source/shared/ipc_events.h) - core1 calls
 * CAMERA_CAPTURE_Deinit(), signals core0, waits for the reply, then draws
 * the overlay / saves the snapshot before CAMERA_CAPTURE_Reinit().
 */
#include <string.h>
#include "fsl_debug_console.h"
#include "board.h"
#include "app.h"
#include "mcmgr.h"
#include "FreeRTOS.h"
#include "task.h"
#include "camera_capture.h"
#include "lcd_display.h"
#include "bbox_overlay.h"
#include "snapshot.h"
#include "spi1_bus.h"
#include "ipc_layout.h"
#include "ipc_events.h"

/* Model's fixed input resolution - can't call AI_MODEL_GetInputWidth/
 * Height() from core1 (model_runner.h's implementation only builds into
 * core0's image). Must match the model actually deployed on core0 - see
 * its own boot log ("AI_MODEL_Init: ... (72x72 input...)"). */
#define AI_MODEL_INPUT_WIDTH  72U
#define AI_MODEL_INPUT_HEIGHT 72U

/* Generous vs. the ~3.9ms NPU inference time actually measured. A timeout
 * here means core0 didn't answer in time - this frame just skips the AI
 * overlay/snapshot check, not a hang. */
#define AI_RESULT_TIMEOUT_MS 100U

/* Identical to main.c's DEMO_ClearScreen() - copied rather than shared
 * since the two builds don't share source files, only headers/drivers. */
static void DEMO_ClearScreen(uint16_t color)
{
    static uint16_t s_clearLine[DEMO_PANEL_WIDTH];
    for (uint16_t i = 0U; i < DEMO_PANEL_WIDTH; i++)
    {
        s_clearLine[i] = color;
    }
    /* Whole multi-call sequence must be atomic against other bus users -
     * see spi1_bus.h. */
    SPI1_BUS_Lock();
    LCD_SetWindow(0U, 0U, DEMO_PANEL_WIDTH - 1U, DEMO_PANEL_HEIGHT - 1U);
    for (uint16_t row = 0U; row < DEMO_PANEL_HEIGHT; row++)
    {
        LCD_PushPixelsOpen(s_clearLine, DEMO_PANEL_WIDTH);
    }
    LCD_EndWindow();
    SPI1_BUS_Unlock();
}

/* Diagnostic: the fps counter alone doesn't prove the pixel data is real -
 * it would keep counting even on a stuck all-zero buffer. A flat
 * min==max reading is the tell for dead/never-written data. */
static void DEMO_LogFrameSignature(const uint16_t *frame)
{
    const uint32_t pixelCount = (uint32_t)DEMO_BUFFER_WIDTH * DEMO_BUFFER_HEIGHT;
    const uint32_t stride     = 97U;
    uint16_t minPixel         = 0xFFFFU;
    uint16_t maxPixel         = 0x0000U;
    uint32_t sum              = 0U;
    uint32_t samples          = 0U;

    for (uint32_t i = 0; i < pixelCount; i += stride)
    {
        uint16_t p = frame[i];
        if (p < minPixel)
        {
            minPixel = p;
        }
        if (p > maxPixel)
        {
            maxPixel = p;
        }
        sum += p;
        samples++;
    }

    PRINTF("Camera: %u samples, pixel range 0x%04X..0x%04X, avg=0x%04X%s\r\n", samples, minPixel, maxPixel,
           (uint16_t)(sum / samples), (minPixel == maxPixel) ? " (flat - dead/no data)" : "");
}

/* Converts the wire-safe ai_ipc_result_t (plain data, no cross-core
 * pointers - see ipc_layout.h) into the ai_model_result_t shape
 * snapshot.h/bbox drawing expect. `out`'s label pointers point INTO
 * `ipc`, so `ipc` must outlive `out` - true at every call site below. */
static void ConvertIpcResult(const ai_ipc_result_t *ipc, ai_model_result_t *out)
{
    out->valid    = ipc->valid;
    out->boxCount = (ipc->boxCount > AI_MODEL_MAX_BOXES) ? AI_MODEL_MAX_BOXES : ipc->boxCount;
    for (uint32_t i = 0; i < out->boxCount; i++)
    {
        out->boxes[i].label  = ipc->boxes[i].label;
        out->boxes[i].x      = ipc->boxes[i].x;
        out->boxes[i].y      = ipc->boxes[i].y;
        out->boxes[i].width  = ipc->boxes[i].width;
        out->boxes[i].height = ipc->boxes[i].height;
        out->boxes[i].score  = ipc->boxes[i].score;
    }
}

/* Cheap rolling hash over a sparse sample of the frame buffer, same
 * stride as DEMO_LogFrameSignature() - used to check whether the buffer
 * is still changing (see the settle-check comment below). */
static uint32_t QuickBufferSignature(const uint16_t *frame)
{
    const uint32_t pixelCount = (uint32_t)DEMO_BUFFER_WIDTH * DEMO_BUFFER_HEIGHT;
    const uint32_t stride     = 97U;
    uint32_t sig              = 0U;

    for (uint32_t i = 0; i < pixelCount; i += stride)
    {
        sig = (sig * 31U) + frame[i];
    }
    return sig;
}

static void CameraLcdTask(void *pvParameters)
{
    (void)pvParameters;

    CAMERA_CAPTURE_Init();
    LCD_Init();
    DEMO_ClearScreen(0x0000U);

    /* NOT wrapped in an outer lock - see sd_spi_disk.c's
     * disk_initialize() comment: locking this whole call broke SD mount,
     * reverted to narrow per-diskio-call locking instead. */
    SNAPSHOT_Init();

    CoreDebug->DEMCR |= CoreDebug_DEMCR_TRCENA_Msk;
    DWT->CTRL |= DWT_CTRL_CYCCNTENA_Msk;
    uint32_t fpsFrameCount      = 0U;
    uint32_t fpsWindowStartCycle = DWT->CYCCNT;
    uint16_t frameSeq            = 0U;

    /* Set right after CAMERA_CAPTURE_Reinit(), cleared once the following
     * frame has been consumed - SmartDMA needs one cycle to resync with
     * the sensor after a fresh Reinit(). */
    bool skipNextFrame = false;

    /* Buffer-content settle check: some saved snapshots came back torn
     * (not truncated - correct file size, but garbled content), tracing
     * to the frame buffer still being mid-write when read, not just a
     * stale frame count (a frame-count-based check was tried first and
     * confirmed NOT sufficient on real hardware). Hash a sparse sample,
     * wait briefly, hash again, and only proceed once two consecutive
     * hashes agree - bounded retries so a genuinely stuck buffer doesn't
     * hang forever. */
#define SETTLE_CHECK_DELAY_MS  2U
#define SETTLE_CHECK_MAX_TRIES 5U

    for (;;)
    {
        if (CAMERA_CAPTURE_IsFrameReady())
        {
            CAMERA_CAPTURE_ClearFrameReady();

            if (skipNextFrame)
            {
                skipNextFrame = false;
                continue;
            }

            /* Stop SmartDMA before reading the frame buffer, restart
             * after - the core0 AI round trip below must fully finish
             * before CAMERA_CAPTURE_Reinit() runs. */
            CAMERA_CAPTURE_Deinit();
            uint16_t *frame = CAMERA_CAPTURE_GetFrameBuffer();
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
